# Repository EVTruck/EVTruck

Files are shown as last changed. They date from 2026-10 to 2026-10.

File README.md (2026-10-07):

# EVTruck

Truck EV conversion bits and parts






## License

Copyright (C) 2026 Stephen Kent and contributors

Licensed under the GNU Lesser General Public License v3.0 or later
([`LGPL-3.0-or-later`](https://github.com/EVTruck/EVTruck/blob/main/COPYING.LESSER)).

## Project template

This project is generated and maintained with [copier-python][copier-python].

[copier-python]: https://smkent.github.io/copier-python

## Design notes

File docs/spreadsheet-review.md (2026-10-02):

# Truck Stuff.xlsx review (2026-10-02)

This is a review of [`truck-stuff.xlsx`](truck-stuff.xlsx), the project spreadsheet as exported from Google Sheets on 2026-10-02. Each problem has a GitHub issue, linked in parentheses.

The truck uses 7 Tesla 5.3 kWh modules (85 kWh pack, 55 lb each), installed in 3 battery boxes.

## What it tracks

| Sheet | What's in it | Key numbers |
|---|---|---|
| Project Management | 10 open tasks (BMS, charger, HV cable length, battery boxes, contactor box, cooling plumbing, data ports) | Only 3 tasks have an owner (Derek: buy modules; John: BMS, charger) |
| Truck specs | Stock truck figures | 2,800 lb curb, 4,400 lb GVW, 1,600 lb payload, 106 hp / 137 ft-lb, ~280 Wh/mile estimate |
| Conversion List | ~50 conversion parts with cost, links, notes, plus a cost-tally log | **$29,014.32** total; batteries $11,485 and motor kit $5,000 are the big items |
| Comparisons | Motor options (HyPer9HV picked), battery options, Tesla pack sizing for 5–8 modules | 7 modules = 159.6 V nominal, 176.4 V max, ~37 kWh |
| Conversion Weights | Parts removed vs. added | Net **+96.5 lb** |
| Truck Costs | Purchase, registration, tires, repair parts | Vehicle $1,913.51 + repairs $694.80 = **$2,608.31** |
| Maintenance | Fluid types and capacities (FS5W71C trans, GL-4/GL-5, DOT 3) | — |

All-in so far: about **$31,600** (conversion list + truck costs).

## Likely errors

1. **Truck Costs F5 ("Truck Cost including tools") double-counts the repair parts.** It's `SUM(F2, D:D)`, but F2 already includes D:D, so it adds $694.80 twice ($3,303.11). It also doesn't pull in any tools. (#15)
2. **Conversion List row 55 has a $147.52 cost with no item name.** It's included in the $29,014 total. (#16)
3. **Battery hose fittings: $298.50 doesn't match its note** ("$22.50 × 2 ports/box × 3 boxes" = $135). (#17)
4. **Comparisons D12: a 6.3 kWh Tesla module listed at $19,000.** Probably a typo (the 5.3 kWh one is $1,580). The "5.6 kWh Tesla" row is empty, and its link actually points to a 6.2 kWh module. (#18)
5. **CALB 180 pack weight uses 5.6 kg per cell, but the lbs column says 55 lb.** One of the two is wrong (5.6 kg is about 12 lb). (#19)
6. **Range math disagrees.** The pack table assumes 2.5 mi/kWh (400 Wh/mile), but Truck specs estimates 280 Wh/mile. At 280 Wh/mile, 7 modules gives about 130 miles, not 93. (#20)
7. **Cost-tally log is out of date.** Last entry (2026-06-18) is $28,614, while the current total is $29,014.32. (#21)
8. **Possible charger double-count.** Row 15 ($1,200) is a 3.3 kW charger + DC-DC combo, and row 32 "BMS/Charger" is another $420. Also, $420 looks low for the EVWest MCU + satellite board noted in Project Management. (#22)

## Incomplete

- **Parts with no cost yet:** HV shrink tubing, safety interlock, inertia switch, low-voltage cutoff, 12V fuses, fuse blocks, KSI relay, radiator, coolant reservoir, coolant lines, power steering, milspec shrink wrap, clutch fork dust cover. The real total will be higher than $29k. (#23)
- **Open questions in the notes:** Does the controller need its own thermostat? Can the BMS handle the interlock and the low-voltage cutoff? (#25)
- **Weight list is missing heavy items:** the battery boxes, contactor box, vacuum pump, charger/DC-DC, heater, new radiator, coolant and pumps. The +96.5 lb is low. Battery modules are estimated at 450 lb, but the 7 modules actually bought weigh 7 × 55 lb = 385 lb. (#24)
- **Truck specs:** the wheel-height labels have no measurements. (#26)
- **Project Management:** most tasks have no owner or priority. "Buy Tesla Modules" is still listed even though the tally says battery pricing was locked in June 2026. The Data Ports note still says "X number of data wires". Columns F/G are still named "Column 1/2". (#26)

## Small stuff

- The Hyper9HV stats say "kWh Peak/Continuous" but mean kW. (#27)
- The AC Motor and throttle reasons say "charge controller" but mean motor controller. (#27)
- Formulas use Google Sheets functions (MINUS, DIVIDE, MULTIPLY). They won't recalculate if the file is opened in Excel. (#27)
- 8 modules (201.6 V max) would exceed the HyPer9HV's 180 V limit, so 7 is the ceiling with this motor.
- The Conversion List total includes about $473 of tools and $216 of replacement parts, so the "conversion" number isn't purely conversion parts.

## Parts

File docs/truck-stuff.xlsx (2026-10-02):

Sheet: Project Management
Task | Location | Owner | Priority | Notes | Column 2 | Column 1
~~Buy Tesla Modules~~ | Desk | Derek | High
~~Source BMS~~ | Desk | John |  | possible https://www.orionbms.com/products/orion-bms-standard | https://evwest.com/mcu-master-control-unit-can-bus-bms-and-charger-controller-by-dilithium-design-and-thunderstruck | The EVWest BMS is also a charge controller, but will also need a satellite board (https://evwest.com/dilithium-bms-satellite for handling the number of batteries we are using. Despite the extra board, this setup is cheaper than the Orion BMS system.
~~Source Charger~~ | ~~Desk~~ | ~~John~~ |  | ~~prefereably one that communicates on CAN~~
~~Determine length of 2/0 cable needed for HV circuit~~
Wire up Motor controller wiring harness
Assemble battery boxes
Assemble contactor box |  |  |  | houses the main contactor, the service disconnect, and other stuff related to the HV circuit
Source Plumbing ports and lines for Battery cooling
wire up BMS to batteries
Source Data Ports for Battery boxes | Desk |  |  | there's X number of data wires per Tesla Module. There is one box with Three modules, and two boxes with two modules. These ports also need to be weatherproof and vibration proof

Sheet: Truck specs
Field | Measurement | Unit | Notes | wheel heights
vehicle curb weight (stock) | 2800 | lbs |  | front driver
vehicle gross weight | 4400 | lbs |  | front passenger
max cargo weight | 1600 | lbs |  | rear driver
current engine torque | 137 | ft lbs |  | rear passenger
current engine horsepower | 106 | hp
rough energy cost | 280 | Wh/mile

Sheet: Conversion List
Total | $29014.32
Category | Conversion Part | Reason | Cost | link | Notes | Total Project Cost
Mechanical | AC Motor | usually come in a kit that includes charge controller | $5000.00 | https://www.evwest.com/catalog/product_info.php?cPath=8&products_id=482 | lots of places sell kits that include a motor and controller | $29014.32
 | motor mount | mount motor to truck frame | $138.33
 | transmission adapter plate | connects new motor to existing transmission. CanEV adapter plate retains use of clutch | $1349.00 | https://www.evwest.com/catalog/product_info.php?products_id=137 | allow for use of original clutch |  | cost tally | date | note
 | throttle | potentiometer to send signal to charge controller | $180.00 | https://www.evwest.com/catalog/product_info.php?products_id=418 |  |  | $26874.30 | 2023-04-02 | start of cost tracking
 | battery cell containment box | protect batteries from getting smacked, insulate from temperatures | $3785.00 | https://amprevolt.com/collections/battery-boxes/products/battery-boxes-2-pack-for-tesla-model-s-battery-modules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 |  |  | $28093.30 | 2023-04-06 | actual cost of battery boxes plus air pressure valves
 | battery box mounts | 1/16th" square tube and sheet metal | $433.00 |  | home depot
 | vacuum pump system | for power brakes | $288.00 | https://www.evwest.com/catalog/product_info.php?products_id=345 |  |  | $27975.30 | 2023-04-12 | deleted something I didn't need
Main Power | battery cells | can be bought piecemeal | $11485.00 |  | https://stealthev.com/product/tesla-module/ |  | $28949.32 | 2023-05-03 | bought stuff for battery modules
 | Tesla Cell Bus Bars | saves space connecting the cells over 2/0 gauge wire | $196.00 | https://stealthev.com/product/stealth-ev-positive-upper-terminal-jumper/ | 1x for front box, 1x for rear driver box, 2x for rear pass box |  | $28614.00 | 2026-06-18 | price locked in for batteries and BMS/charger
 | HV cable connectors | for creating a modular battery system | $432.00 | https://amprevolt.com/collections/battery-accessories/products/heavy-duty-sealed-power-connector-one-male-female-set | 2x per box, 3x boxes
 | motor controller thermostat/relay | monitors motor controller temp and can switch on cooling unit | $50.00 | https://www.evwest.com/catalog/product_info.php?products_id=154&osCsid=72547585d10818d1a46bcac51a4df5a1 | do I need this? Does Motor controller have a thermostat?
 | 12V battery charger/DC-DC convertter | 2-in1. Any good? | $1200.00 | https://stealthev.com/product/3-3kw-aircooled-charger1kw-dc-dc-converter-2/
 | charging port | for connecting to external power | $125.00 | https://www.evwest.com/catalog/product_info.php?cPath=35&products_id=433
 | charge port control board | charger has a protocol that board handles | $52.00
 | main disconnect | for main pack | $160.00 | https://www.evwest.com/catalog/product_info.php?products_id=538&osCsid=89b1cd88fc4573fb9d51f391184ddbbc
 | home charging cable | charge at home | $285.00 | https://www.electriccarpartscompany.com/j1772-connectors-16a-level-1-120v-ev-charger-plug-with-electrical-control-box
 | power cables | for routing power. Super thick gauge industrial shit | $450.00
 | power cable terminals | for connecting cables to terminals. Need 4 per module box (2 for battery terminals, 2 for module fuse) | $50.00
 | HV shrink tubing | for covering cable-terminal connection
 | main contactor | another safety thing (came with motor & controller) | $0.00
 | Fuse(s) | safety | $258.00 |  | one for each battery module
 | fuse mounting blocks | safe way to mount fuses | $144.00 |  | one for each battery module
 | 12v battery | for shit like headlights and radio. Can re-use what I have | $0.00
 | safety interlock | keeps the vehicle from driving while plugged in |  |  | can BMS/charger handle this?
 | inertia switch | disables things in the event of an accident |  |  | pick a part?
 | HV shunt | for measuring current draw(?) | $67.00 | https://www.evwest.com/catalog/product_info.php?products_id=112
 | low voltage cutoff switch | turns off if the voltage is dangerously low to prevent motor damage |  |  | would/could this be handled by BMS?
 | PRV vent blowoff valve | emergency gas vent. Prevents explosions if the batteries catch fire | $252.00 | https://amprevolt.com/collections/battery-boxes/products/battery-pack-prv-vent-blow-off-valve
 | BMS/Charger | for managing/charging batteries | $420.00
12V Wiring | fuses | 30 amp for DC/DC converter, 30 amp for charger, 10 amp for KSI relay
 | fuse blocks | holds the fuses |  |  | 3x
 | KSI relay
Plumbing | Radiator | fo cooling coolant |  |  | could be small like for ATVs.
 | coolant pumps 2x | for keeping charge controller cool | $100.00 |  | one for motor/controller, one for batteries. Try to get ones that are quiet. Pumps are $40-60, with salvaged Tesla pumps coming in at ~$150
 | coolant reservoir | holds the coolant, should also be a place to trap air bubbles
 | g48 coolant | coolant | $22.00 | https://www.oreillyauto.com/detail/c/zerex/oil--chemicals---fluids/antifreeze/antifreeze---coolant---vehicle-specific/df3a6469dc0a/zerex-1-gallon-blue-50-50-a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 | SUperFastMatt used it in his tesla jag
 | coolant lines | run coolant from heat exchanger to batteries
 | battery module hose fittings | attachment points for coolant in & out | $298.50 | https://amprevolt.com/collections/battery-boxes/products/bulkhead-compression-fitting-kit | $22.50 * 2 ports/box * 3 boxes
 | coolant manifolds | run coolant in paralel through multiple modules in one box | $98.00
 | inline fluid heater for battery coolant | warms batteries during cold times so they can stay within operating temp | $60.00 | https://evwest.com/in-line-fluid-heater-from-electric-smart-car
Amenities | heater | WA law requires cars to have windshield defogging/defrosting capability | $800.00
 | power steering | make it easier to steer
Tools | engine hoist | lifts the engine out of the chassis | $359.00 | harbor freight. I bought a 2 year warranty in case I do something stupid.
 | scale | for weighing parts that come off the truck | ~~$0.00~~ | got one for free at work
 | hydraulic crimper tool | for crimping high voltage cables | $50.00 | https://www.amazon.com/Hydraulic-Crimper-Battery-Terminal-Crimping/dp/B07QVBD6VM?th=1
 | milspec shrink wrap (with glue) | for shrink wrapping terminal ends. Glue keeps moisture out
 | three-prong gear puller | I fucked up the first attempt at attaching the motor's hub, and I needed this to pull the hub off to try again | $24.24
 | 1/2" drive metric sockets | needed to help unbolt flywheel from engine | $39.67
Replacements | Carrier Bearing | holds the driveshaft in place. Current one is falling apart | $39.68 | https://www.autozone.com/drivetrain/driveshaft-center-support/p/duralast-driveshaft-center-support-hb6/136707_0_0
 | clutch | shit's old and worn | $176.38
 | clutch fork dust cover | keeps stuff out of the trans bell housing
 |  |  | $147.52

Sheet: Comparisons
Motor Name | Horsepower | Torque (ft/lb) | Max Voltage | Peak Amps | Nominal Amps | Continuous RPM | Max RPM | weight (lbs) | RPM sensor | Case Length (in.) | Cost | URL
HPEVS AC-51 | 88 | 108 | 171 |  |  | 5000 | 10000 | 115 | no |  | $5000.00
NetGain HyPer9 | 120 | 172 | 132 | 750 |  | 5500 | 8000 | 120 | yes | 13.75 | $4600.00
NetGain HyPer9HV | 120 | 172 | 180 | 500 |  | 5500 | 8000 | 120 | yes | 13.75 | $4835.00 | included with motor kit
Battery Name | Capacity (Ah) | Continuous Output | Cell Cost | Minimum Voltage | Nominal Voltage | Max Voltage | weight (kg) | weight (lbs) | 180V Pack Size | 180V Pack Weight (lbs) | 180V Pack Cost | HxWxL (in.) | Link
CALB 180 | 180 |  | $259 |  | 3.2 |  | 5.6 | 55 | 56.25 | 693 | $14568.75 | 11.8 x 2.8 x 7.17 | https://www.evwest.com/catalog/product_info.php?cPath=4&products_id=50
LG Chem Super Cells | 63 |  | $499.00 |  | 25.5 |  | 8.9 |  | 7.06 | 138.21 | $3522.35 | 4.125 x 5 x 16.75 | https://www.evwest.com/catalog/product_info.php?cPath=4&products_id=534
5.6 kWh Tesla |  |  |  |  |  |  |  |  |  |  |  |  | https://stealthev.com/product/tesla-6-2-kwh-module-from-90kwh-pack/
5.3 kWh tesla | 232 | 225 | $1580.00 | 18 | 22.8 | 25.2 | 24.9 | 55 | 7.9 | 432.47 | $12473.68 | 3.1x11.9x26.2
6.3kWh Tesla |  | 225 | $19000.00 | 18 | 22.8 |  |  | 65
LFP 302 | 302 |  | $334.60 | 2.5 | 3.22 | 3.65 | 5.5 |  | 55.9 | 676.40 | $18704.35
Hyper9HV stats |  |  |  | Pack Configuration | Min Voltage | nom. voltage | Max Voltage | capacity (Ah) | kilowhatt-hours | est. max travel dist. | serial cell count
kWh Peak | 90 @ 170V | so ~529 amps |  | 5 | 90 | 114 | 126 | 232 | 26.448 | 66.12 | 30
kWh Continuous | 38 @ 3600 RPM | ~223.5 amps |  | 6 | 108 | 136.8 | 151.2 | 232 | 31.7376 | 79.344 | 36
 |  |  |  | 7 | 126 | 159.6 | 176.4 | 232 | 37.0272 | 92.568 | 42
 |  |  |  | 8 | 144 | 182.4 | 201.6 | 232 | 42.3168 | 105.792 | 48

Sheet: Conversion Weights
item | weight | Notes | change in weight | 96.5
gas engine | -350 | (plus clutch)
exhaust system | -57
gas tank | -65 | estimate: 60 lbs of fuel + ~5 lbs for tank itself
radiator | -1 | estimate
starter motor | -9.5
Hyper9 motor | 184 | (plus clutch & trans adapter)
motor controller | 7
Battery Modules | 450 | estimate
old radiator fluid | -9.5
air intake | -6.5
AIV case | -1.5
alternator | -9.5
distributor | -6 | extra sensors. pretty hefty
some sort of vapor tank | -1.5
old 12v battery | -37
HV cables | 5 | estimate
battery box mounts | 12 | estimate
forward gas tank shield | -7.5

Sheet: Truck Costs
Vehicle Costs (incl. maintenance) | Amount | Replacements | Part Cost | Total Replacement Cost | Total Truck Cost | Conversion Kit | Price | Contents | link
purchase price | $1000.00 | passenger side mirror | $37.00 | $694.80 | $2608.31 | ev4u AC-51 | $3975.00 | motor, motor controller, wiring, connectors | http://www.ev4unow.com/ConversionComponents.html
Title and registration | $329.50 | seatbelts | 125.06 |  |  |  |  |  | https://www.electricmotorsport.com/ac-50-kit.html
lug wrench | $22.99 | brake drums (due to previous owner driving with P-brake engaged) | 131.77 | Total Vehicle Costs | Truck Cost including tools
new battery | $130.00 | nuts and bolts for parking brake mount ( 3d printed mount to replace snapped one) | $1.69 | $1913.51 | $3303.11
new tires | $415.33 | outer door handles | $9.85
belts | $7.70 | windshield handle clips | $3.84
fuel line cleaner | 7.99 | driver side door hinge pins | $14.30
 |  | distributor cap | $31.99
 |  | distributor rotor | $21.99
 |  | front brake pads | $24.00
 |  | A/C Belt | $22.99
 |  | brake fluid | $6.99
 |  | vacuum hose | $10.50
 |  | spark plugs | $19.92
 |  | fuel filter | $15.99
 |  | spark plug wire | $37.42
 |  | turn signal lever | $15.50
 |  | interior plastic | $18.00
 |  | rear shocks | $146.00

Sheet: Maintenance
Thing | fluid category | fluid type | capacity | transmission type | FS5W71C
Manual Transmission Gear |  | API GL-4*2 | 2 litres
differential gear |  | API GL-5*2 | 1.5 litres
manual steering gear |  | API GL-4*2 | 0.33 litres
brake fluid |  | DOT 3
clutch fluid |  | DOT 3

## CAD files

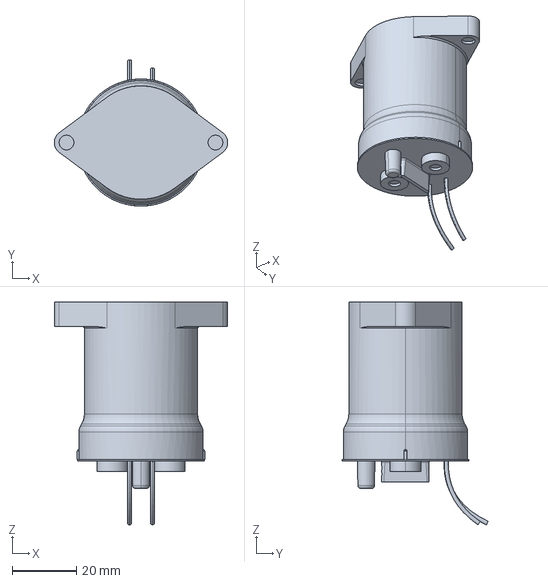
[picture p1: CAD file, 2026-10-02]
evtruck/assets/TE-LEV100A4ANG.step
53.8 x 45.4 x 69.2 mm

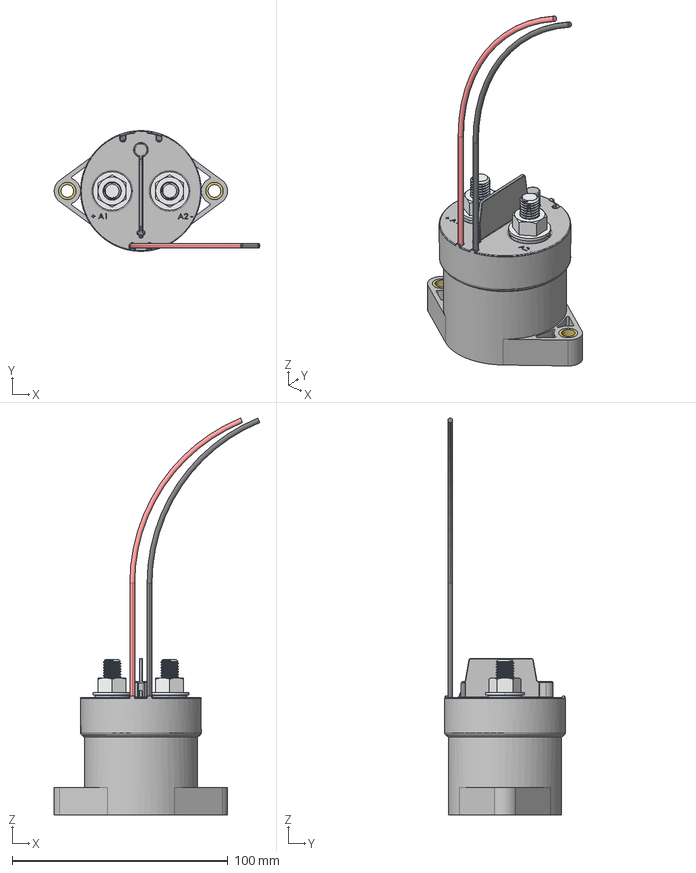
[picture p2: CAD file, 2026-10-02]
evtruck/assets/sensata-gigavac-gv200-series-open-contactors-drawing-updated.step
95.4 x 56.0 x 184.2 mm
GV200_step_121716
GV200_step_121717
GV200_step_121718
GV200_step_121719
GV200_step_121720
GV200_step_121721
GV200_step_121722
GV200_step_121723
GV200_step_121724
GV200_step_121725
GV200_step_121726

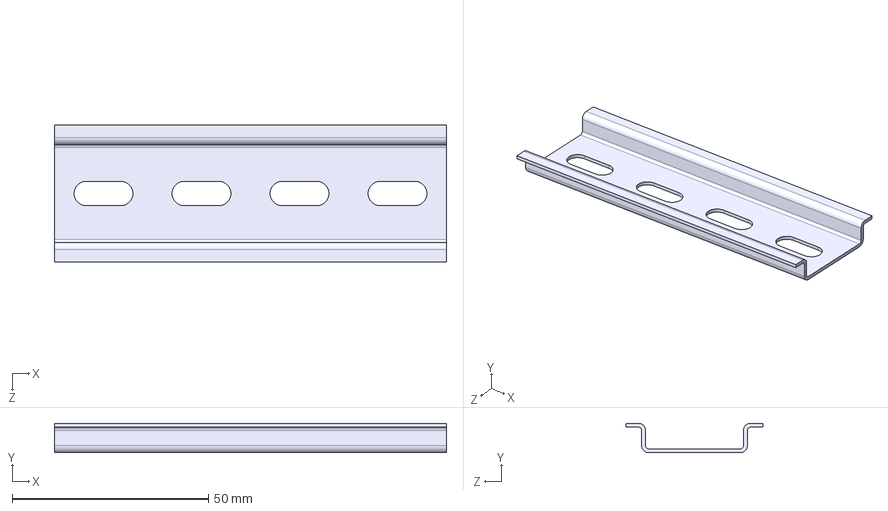
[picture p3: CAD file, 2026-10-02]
evtruck/assets/dinr135-010.step
100.0 x 7.50 x 35.0 mm

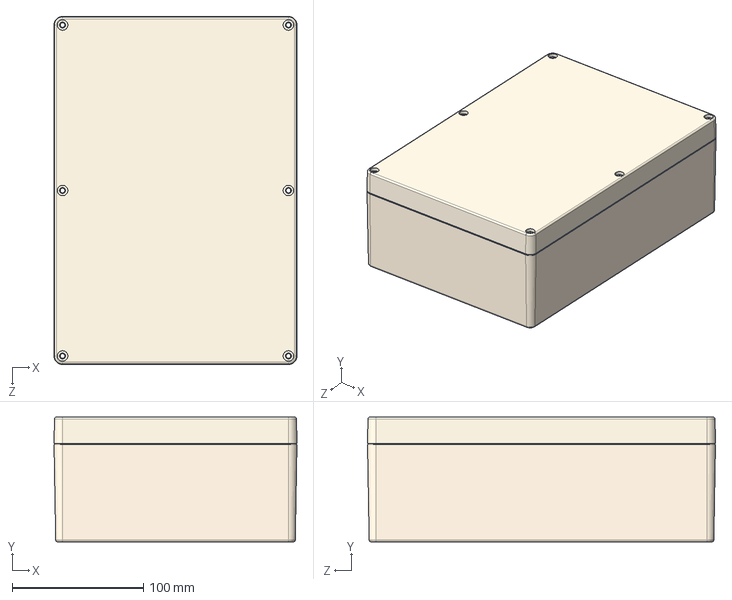
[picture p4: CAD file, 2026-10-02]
evtruck/assets/PN-1335.STEP
185.0 x 95.0 x 265.0 mm
1335-C
1335-B

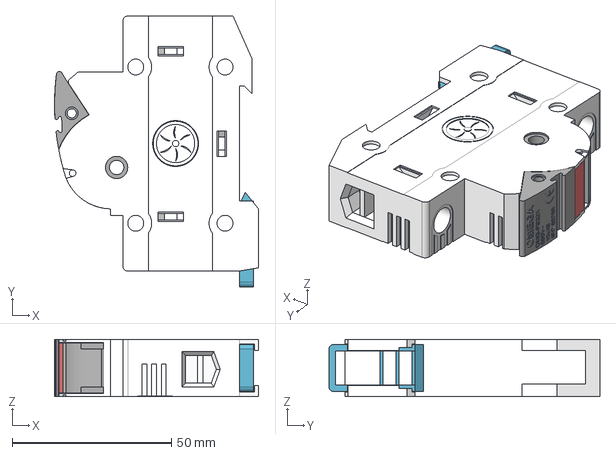
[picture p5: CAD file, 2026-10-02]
evtruck/assets/fuse-holder.step
64.0 x 85.0 x 18.0 mm

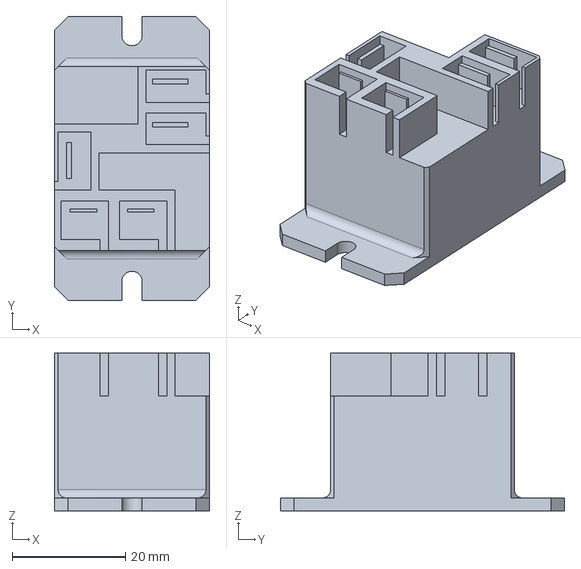
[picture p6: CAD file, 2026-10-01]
evtruck/assets/T9AP1D52-12.step
27.4 x 50.3 x 27.9 mm

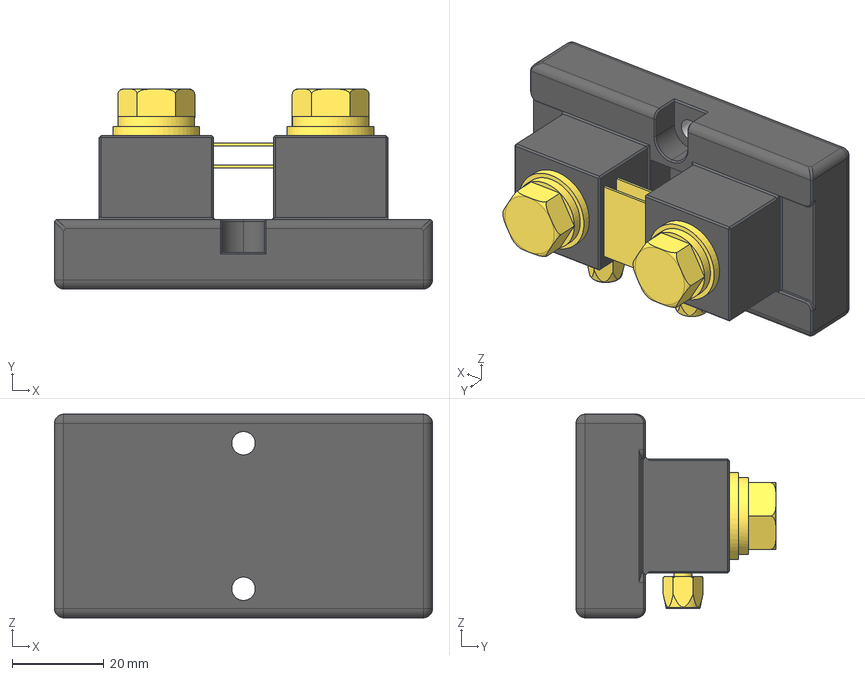
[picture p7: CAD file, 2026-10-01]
evtruck/assets/RSB-600-50-reexported.step
82.6 x 43.7 x 44.5 mm
RSB-600-50
RSB-600-001
RSB-600-002
RSB-600-003
RSB-600-004

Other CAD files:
evtruck/assets/sensata-gigavac-gv200-series-open-contactors-drawing-reexported.step
evtruck/assets/sensata-gigavac-gv200-series-open-contactors-drawing.STEP

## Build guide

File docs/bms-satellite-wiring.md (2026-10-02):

# Wiring 3 Dilithium satellites to the Thunderstruck MCU v1.0

Layout: 3 battery boxes with 2, 2 and 3 Tesla 6S modules (12 / 12 / 18 cells), one satellite per box.

Sources (Thunderstruck):
- MCU wiring diagram: https://www.thunderstruck-ev.com/images/companies/1/Circuits/MCU-Basic-Wiring.pdf?1672268007712
- MCU manual: https://www.thunderstruck-ev.com/images/companies/1/BMS/MCU-Manual.pdf
- BMSC manual (same BMSS24 hardware): https://www.thunderstruck-ev.com/images/companies/1/BMS/BMSC-Manual.pdf
- Harness test guide: https://www.thunderstruck-ev.com/images/companies/1/BMS/BMSHarnessVerify-Safety1.pdf?1680799098478
- EVWest Tesla tap board pinout: https://www.thunderstruck-ev.com/images/product/Tesla%20Model%20S%205.3%20BMS%20Board%2022.pdf?1785369108394

Items marked *(inferred)* are not stated in the docs. Get Thunderstruck to confirm them before relying on them.

## 1. Communication chain (IsoSPI)

Daisy-chain all three satellites off **port A** on MCU Connector A:

```
MCU IPO_A (pin 6) ──► Sat 1 IPI      Sat 1 IPO ──► Sat 2 IPI      Sat 2 IPO ──► Sat 3 IPI
MCU IMO_A (pin 7) ──► Sat 1 IMI      Sat 1 IMO ──► Sat 2 IMI      Sat 2 IMO ──► Sat 3 IMI
```

- Use one **twisted pair** per hop. The terminals take 20 to 24 AWG wire, and 20 AWG stranded is recommended. Route the pairs away from motor, controller and traction cables, not parallel to them.
- No terminating resistors are needed, because they are built into every Dilithium device.
- Leave Sat 3's output unconnected.
- Port A takes up to 8 measurement devices (LTCs). Each BMSS24 has 2 LTCs and each BMSS18 has 1, so 3 satellites fit on port A alone. Port B (pins 8 and 9) is available if one box is far away, but the docs don't require using it.
- LTCs are numbered A1, A2 and so on in chain order. Cell order can be fixed later with `cmap`.
- The satellites take no 12V. They are powered by the cells they measure, and only the MCU gets 12V and GND.

## 2. Cell harness per box

Wire each harness in series order, starting at the box's most negative point:

- w0 / C0 → the first module's **C1-** (EVWest board pos 8, black)
- w1 to w6 → the first module's **C1+ to C6+** (pos 10, 7, 11, 6, 12, 5)
- w7 to w12 → the second module's C1+ to C6+, and so on

Rules:
- A cell group must **not span a fuse, contactor or service disconnect**. If that device opens while the harness is connected, the satellite can be destroyed. With one satellite per box this holds as long as no fuse or disconnect sits *inside* a box. *(inferred)*
- If a group has fewer cells than the satellite has inputs, tie the unused top inputs to the last positive tap.
- Minimum group size is 4 cells on a BMSS24 LTC and 6 cells on a BMSS18.
- Only one architecture can be set per MCU, so don't mix BMSS24 and BMSS18 satellites. *(inferred)*
- Thermistors: each LTC takes 5. Find the Tesla pairs on pos 1 to 4 (5 to 10 kΩ) and enable them with `enable th`.

**Satellite type:**
- **BMSS18:** one LTC per box, carrying 12, 12 and 18 cells. Tie the top 6 inputs together in each 12-cell box.
- **BMSS24 (2 LTCs each):** in the 12-cell boxes, use 6 + 6 so both LTCs are powered. In the 18-cell box, use 12 + 6, split at a module boundary.

## 3. Test before plugging in

1. **Test every harness** on the matching tester board: the 12-cell board for BMSS24, the 18-cell board for BMSS18. With the meter's negative lead on C0, voltage should rise by one cell at each pad. A miswired harness can permanently destroy the satellite.
2. The 18-cell box can reach about 75V (18 × 4.2V). Work on a nonconductive surface with taped probes.
3. Plug a harness into its satellite **last**, and unplug it **first** before changing any pack connections.

## 4. Configure the MCU (serial terminal, 115200 baud)

```
bms
set arch ltc18        (or ltc12 for BMSS24)
show ltc              (check that all LTCs are detected)
show cells            (check that every cell reads plausibly)
set cmap A1 1 1 ...   (only if chain order differs from cell order; check the syntax in the manual)
enable th all
lock                  (saves the cell census and clears NOTLOCKED)
```

Thunderstruck can confirm the exact `cmap` syntax and the IsoSPI connector part number: connect@thunderstruck-ev.com, 707-578-7973.

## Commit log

2026-10-01 Add mounting holes for fuse block
2026-10-01 Update fuse block location and orientation in contactor box
2026-10-01 Add shunt component
    [RSB-600-50-reexported.step]
2026-10-01 Add mounting holes for shunt
2026-10-01 Add relay component to contactor box
    [T9AP1D52-12.step]
2026-10-01 Add mounting holes for relay
2026-10-01 Make mounting holes printable with plate printed right side up
2026-10-02 Remove unused `Assets.FUSE_BLOCK`
    Fixes https://github.com/EVTruck/cad/issues/31
2026-10-02 Add project spreadsheet and review notes
    Add the Truck Stuff spreadsheet (exported 2026-10-02) and a review of
    its costs, specs and gaps. Each problem links to its GitHub issue
    (#15 to #27).
    Claude-Session: https://claude.ai/code/session_01UXAig8DRYxcAXxD9WYDsZp
    [truck-stuff.xlsx]
2026-10-02 Point repository links at EVTruck/cad
    Replace stale smkent/truck-ev URLs in the README badges, project
    metadata, contributing guide and mise init task.
    Closes #30
    Claude-Session: https://claude.ai/code/session_01L82SqdCnEVBoGUnjd2bcD6
2026-10-02 Rename Python project from `truck-ev` to `evtruck`
    [PN-1335.STEP, RSB-600-50-reexported.step, T9AP1D52-12.step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]
2026-10-02 Update repository name references from `cad` to `EVTruck`
2026-10-02 Add BMS satellite wiring guide for the Thunderstruck MCU
    Claude-Session: https://claude.ai/code/session_01TmBYL6beymndSHoD6g5fRv
2026-10-02 Update contactor box component mounting locations
2026-10-02 Add 12V contactor to contactor box model
    [TE-LEV100A4ANG.step]
2026-10-16 Reround plate corner offsets for arbitrary plate thickness
2026-10-16 Increase plate thickness to 8mm with full 5mm sunk depth
2026-10-16 Add contactor base bolt holes, fit guides
2026-10-16 Update contactor bolt head mount holes to be printable upside down
2026-10-16 Add underside bolt holes for other parts
2026-10-16 Adjust 12V contactor, relay locations
